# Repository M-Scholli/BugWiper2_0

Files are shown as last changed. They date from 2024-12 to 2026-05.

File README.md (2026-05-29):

## New ESP32-S3 Version

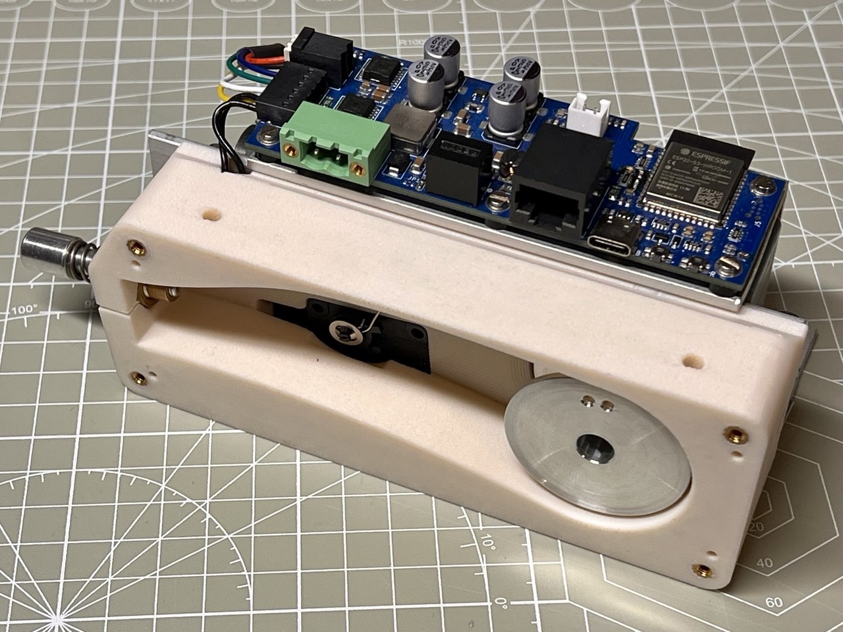
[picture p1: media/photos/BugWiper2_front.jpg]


The new version of the BugWiper system is a complete redesign of the hardware and software to improve the performance, reliability and features of the system. The new design is based on the ESP32-S3 micro controller. The new design also includes a new motor with higher torque, a self locking gear and a motor encoder to measure the motor position and speed. The new design also includes a new software architecture that allows for more advanced features like programmable cable length, soft direction change of the motor at the wingtip, slow down the motor before reaching the fuselage and logging of all sensor data on an SD-card for later analysis and optimization of the system.

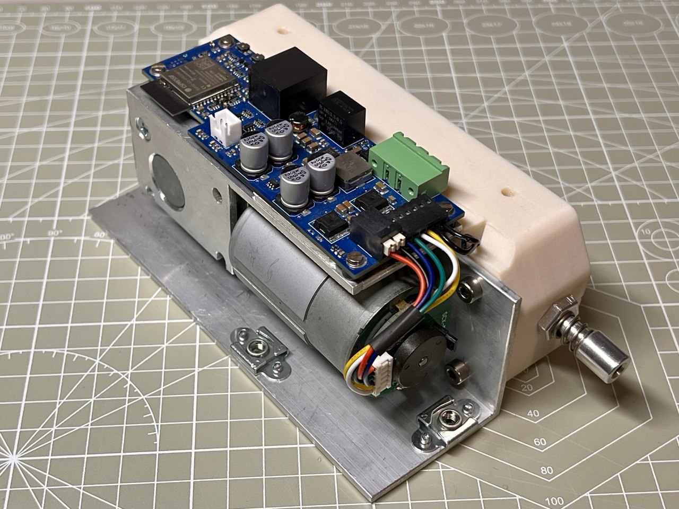
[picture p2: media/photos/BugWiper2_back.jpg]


The BugWiper System cleans the wings in around 30 seconds as shown in this graph:
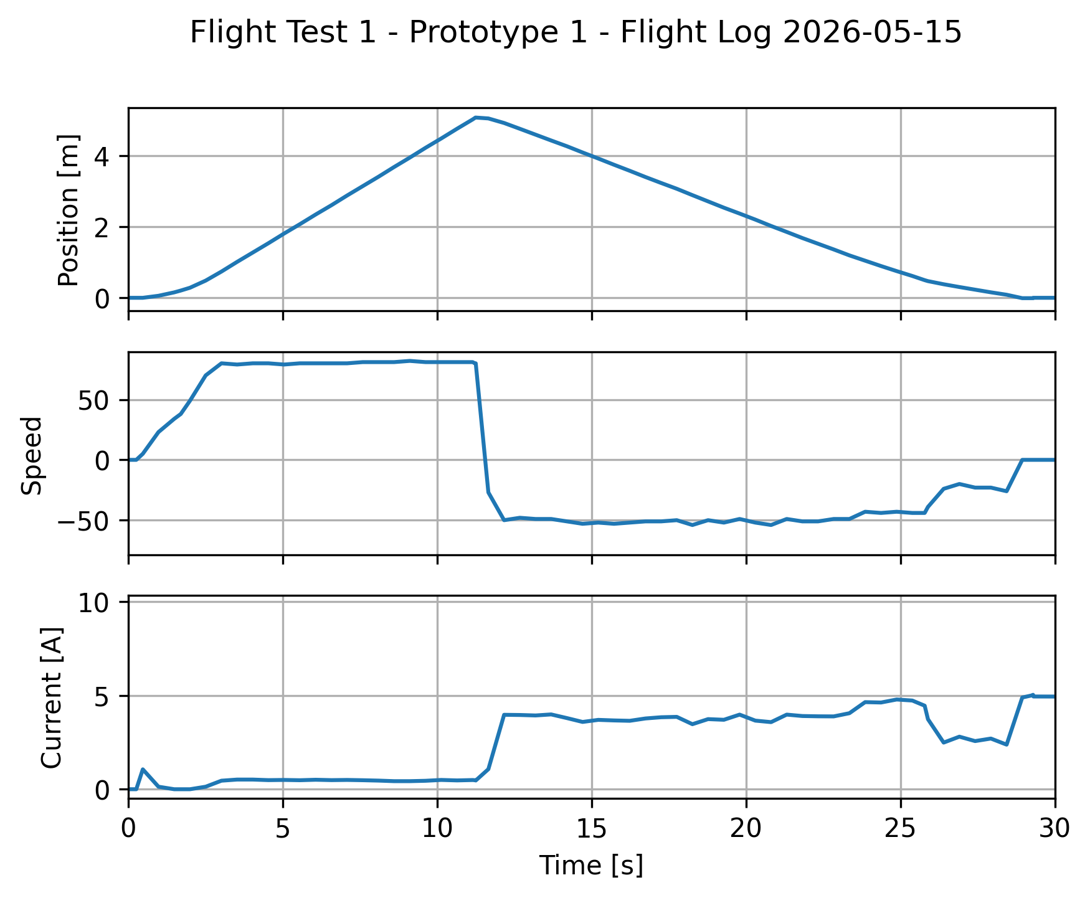
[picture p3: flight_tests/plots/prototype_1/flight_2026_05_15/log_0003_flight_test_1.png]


The documentation of the new version is still in progress, but you can already find some information about the hardware and software design in the following documents:
 [Documentation](./docs/doc.md)

 The user manual can be found here:
 [User Manual](./docs/user_manuel.md)

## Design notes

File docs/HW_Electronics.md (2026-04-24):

# Electronics

## PCB Design
- Designd in KiCAD 7
- 4 Layer PCB

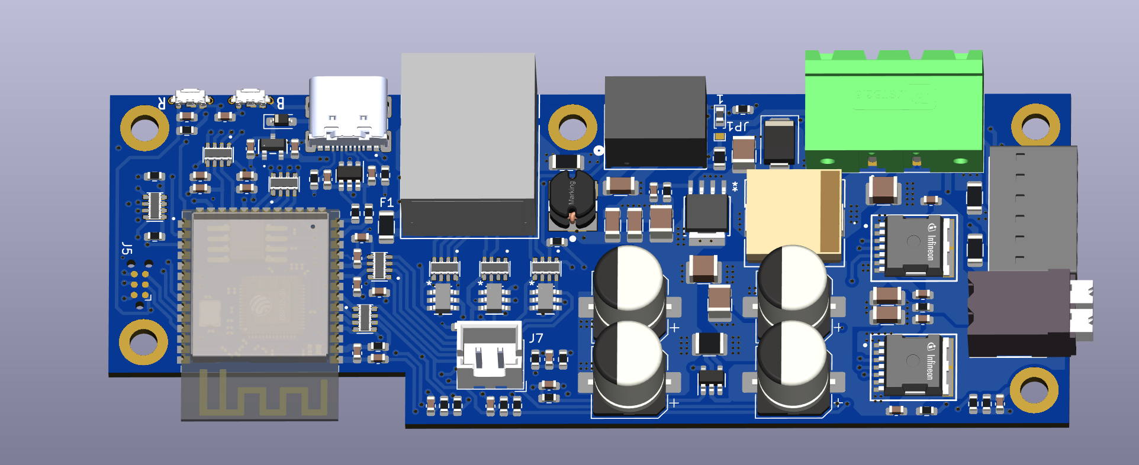
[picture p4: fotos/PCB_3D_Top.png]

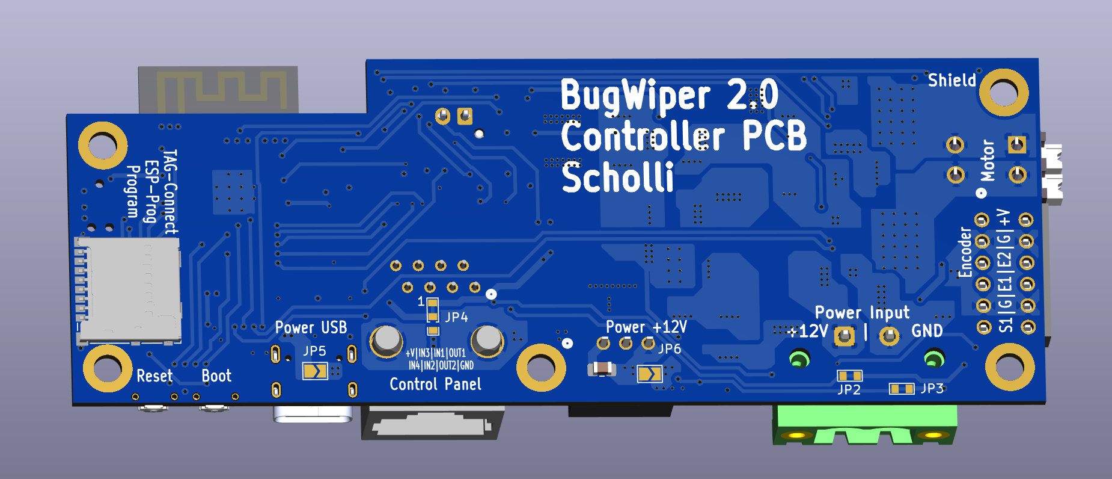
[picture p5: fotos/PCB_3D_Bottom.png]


## Circuit Diagram
[Schematics Controller PCB.pdf](../Hardware/ControllerPCB/BugWiper_ControllerPCB_SDT.pdf)
[Schematics Panel PCB.pdf](../Hardware/PanelPCB/BugWiper_Control_Panel_PCB_SDT.pdf)

## Key Components

| Name | Manufacturer|Function | Link |
| :---: | :---: |:---: | :----: |
|ESP32-S3-WROOM-1-N16R8|Espressif|Controller|https://mou.sr/4j57iPN|
|BTN9960LV|Infineon|Half Bridge with controller||
|INA180A2|texas instruments|Current Sense Amplifier||
|SQJ146ELP-T1_GE3|Vishay|N-MOSFET||
|UJ20-C-H-G-SMT-1-P16-TR |Same Sky|USB-C Connector|https://mou.sr/4adiw0M
| 1N5819HW-7-F | Diodes Incorporated|Schottky Diode 1A | https://mou.sr/3PtqzN7
|82400102|Würth|TVS Diode Array|
|EVP-AT2L1B000|Panasonic|switch|https://mou.sr/4j0OPno|

## Bill of Material
[BOM Controller PCB.csv](../Hardware/ControllerPCB/BugWiperPCB.csv)
[Bom Panel PCB.csv](../Hardware/PanelPCB/Panel/Panel.csv)

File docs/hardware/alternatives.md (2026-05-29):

# Suggestions for alternative hardware selection

## Controller
I suggest to use a ESP32-WROOM-32 or ESP32-S3-WROOM.

## ESP32-WROOM-32
Simple and small solution:
- diymore ESP32 WROOM 32 Nodemcu https://amzn.eu/d/j1bOF2C
### Pinout SP32-S3-DevKitC-1 N16R8:
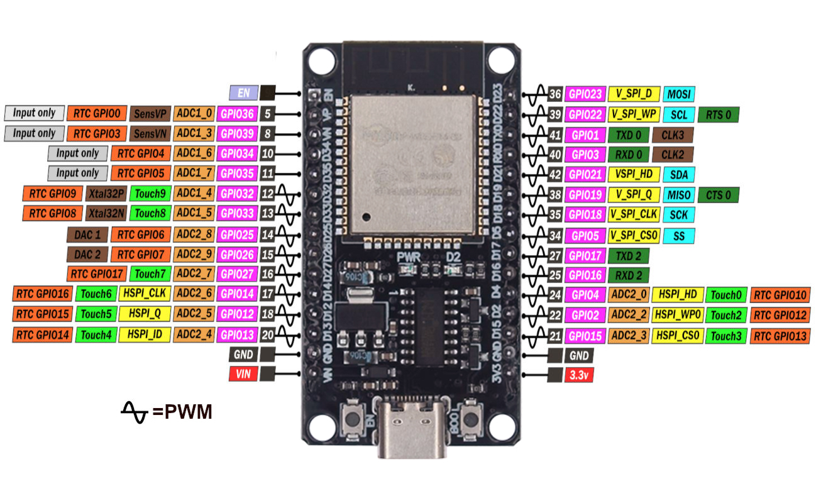
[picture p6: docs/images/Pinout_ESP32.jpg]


### CH340 Driver (USB-Serial)
https://www.arduined.eu/ch340-windows-10-driver-download/

## ESP32-S3-WROOM
newer ESP-S3:
- iHaospace 2 x ESP32-S3-DevKitC-1 N16R8 16Mb Flash, 8MB PSRAM https://www.amazon.de/dp/B0D1CBV999
### Pinout SP32-S3-DevKitC-1 N16R8:
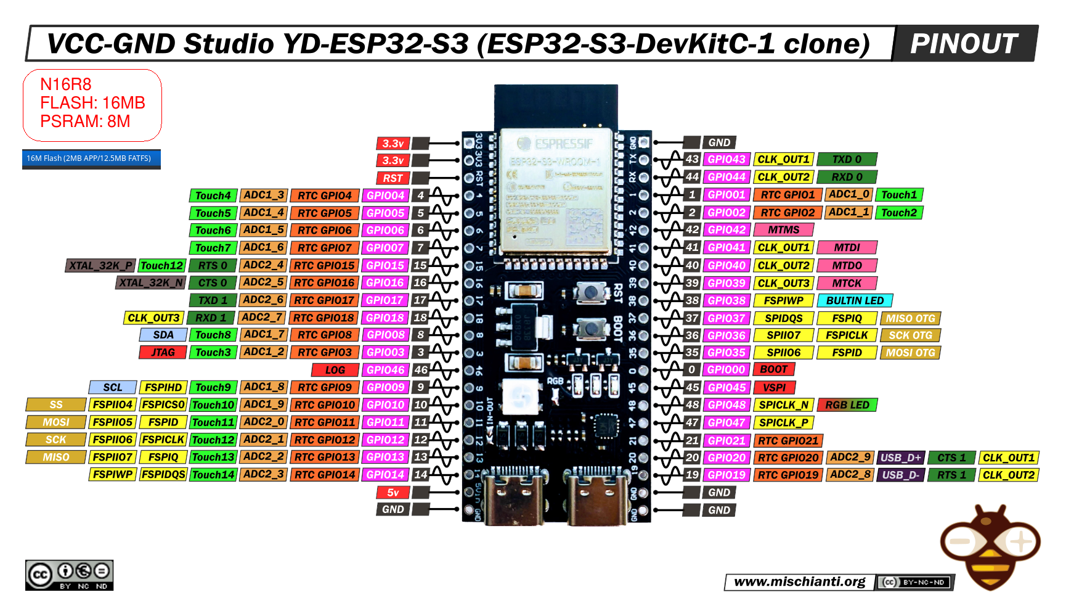
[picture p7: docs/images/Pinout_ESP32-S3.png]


## Motor controller / H-Bridge
### Complete Motor Driver PCB
#### IBT_2 BTS7960B 43 A Motor Driver: 
- https://www.makershop.de/module/motosteuerung/double-bts7960/
- https://www.amazon.de/dp/B09HGBM5D2

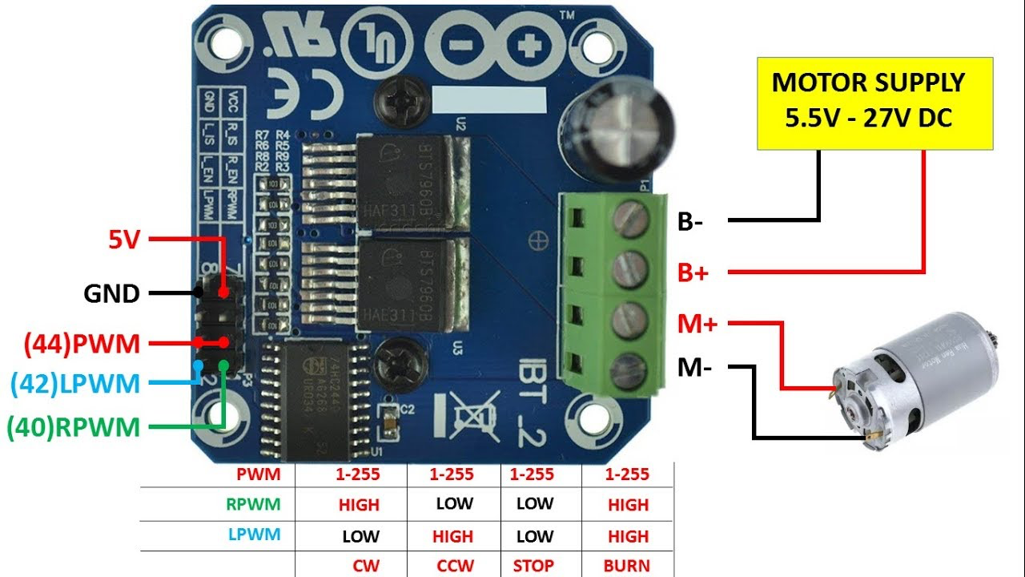
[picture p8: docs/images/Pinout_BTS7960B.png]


Specs:
- Max Current: 43 A
- Voltage Range: 5 V - 27 V
- Max PWM freq.: 25 kHz
- Current sensing output

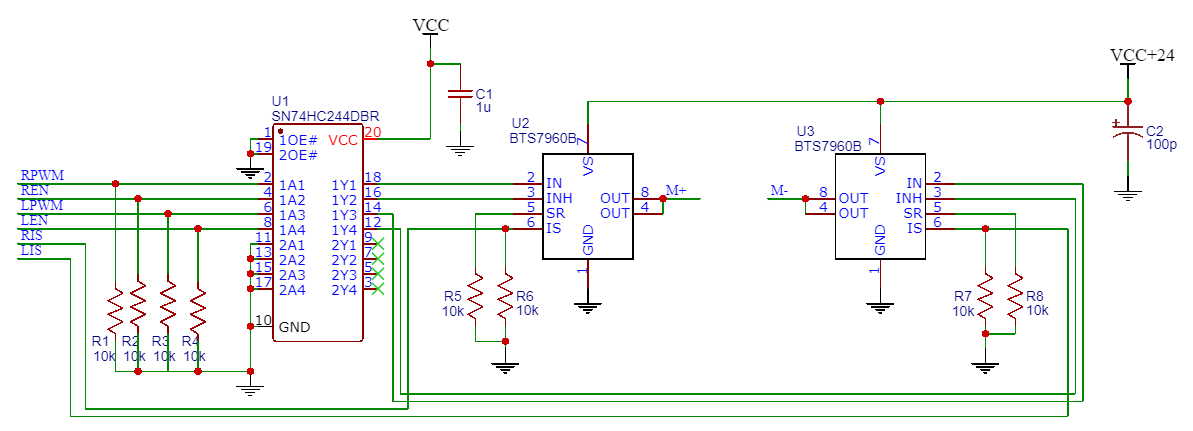
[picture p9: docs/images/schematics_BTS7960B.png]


### Others
- IBT_2 BTS7960B 43 A Motor Driver: https://www.amazon.de/dp/B09HGBM5D2
- 12V DC 200rpm High Torque Geared Electric Motor: https://www.amazon.de/gp/product/B00T48KC1Q 
- A3144 Linear Hall Effect Sensor: https://www.amazon.de/dp/B0BQ2Z335H
- Self-Adhesive Magnets 8 x 1 mm : https://www.amazon.de/dp/B0BJQ918KX

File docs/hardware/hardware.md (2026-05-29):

# Hardware Overview

- [Motor Selection and Tests](./motors.md)
- [PCB Design of the Controller and Panel PCB](./electronics.md)
- [Mechanical Construction](../mechanics/construction.md)
- [Suggestions for alternative hardware selection](./alternatives.md)
- [Documentation first Prototype](../testing/prototypes.md)

## Electronics / PCB Designs

### Motor Controller PCB


[More info here](./electronics.md)

### ControlPanel PCB
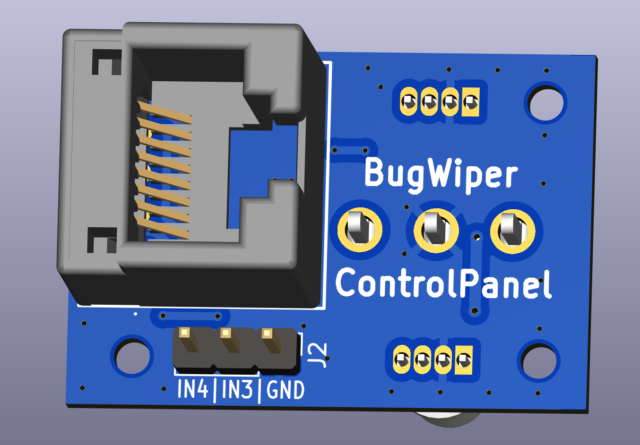
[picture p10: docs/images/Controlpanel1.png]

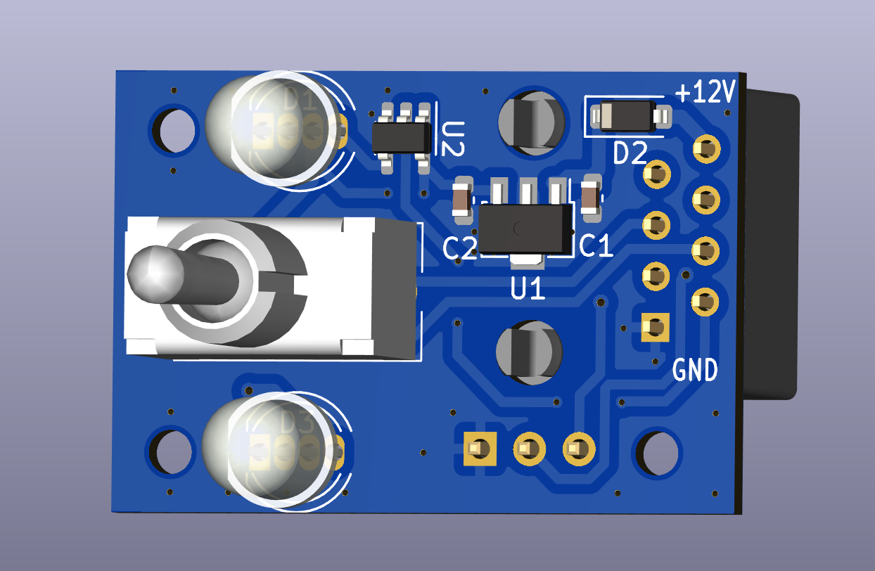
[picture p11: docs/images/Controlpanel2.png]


## Mechanical Construction
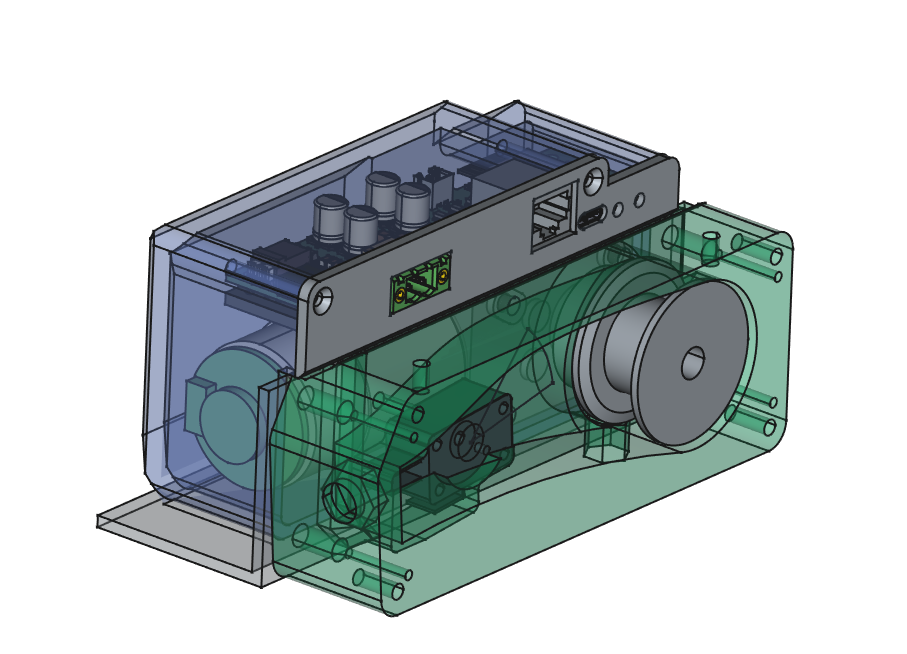
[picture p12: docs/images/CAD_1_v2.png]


- [Mechanical Construction](../mechanics/construction.md)

## Motor
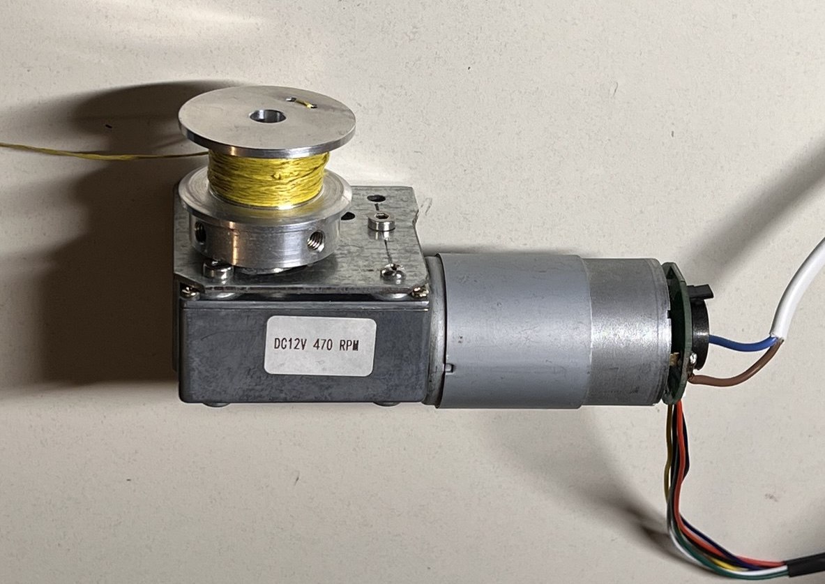
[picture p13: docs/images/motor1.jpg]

[More Details and Motor tests here](./motors.md)

## Old Version
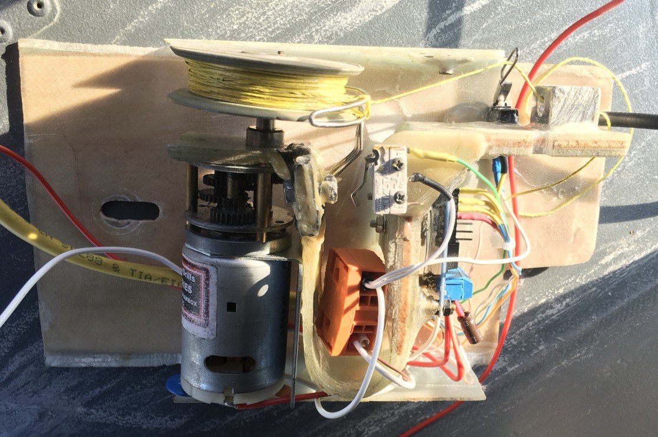
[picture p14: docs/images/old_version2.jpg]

[More information and documentation of the old prototypes and there problems can be found here](../old_version.md)
Also see the github repository of the old version:
[Old Version Repository](https://github.com/M-Scholli/BugWiper)

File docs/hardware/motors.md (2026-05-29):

# Motor

## Motor recommendations and comparison
In the Hardware folder of this repo is a [Excel](../../Hardware/Motor_comparison.xlsx)  and CSV file witch lots of motors and its comparison and the calculated winding times and forces at different drum diameters.
#### Motor selection criteria:
- Motor RPM between 250 to 450 RPM. This allows a cleaning time around 30 seconds with a spool diameter between 20 mm and 40 mm
- Motor Torque / Motor Power high enough to reach a pulling force of 3 to 5 kg
- high friction / high gear ratio / high no load current or self locking gear that the bug wiper wings don't pull out the rope when the motor is shut down. 

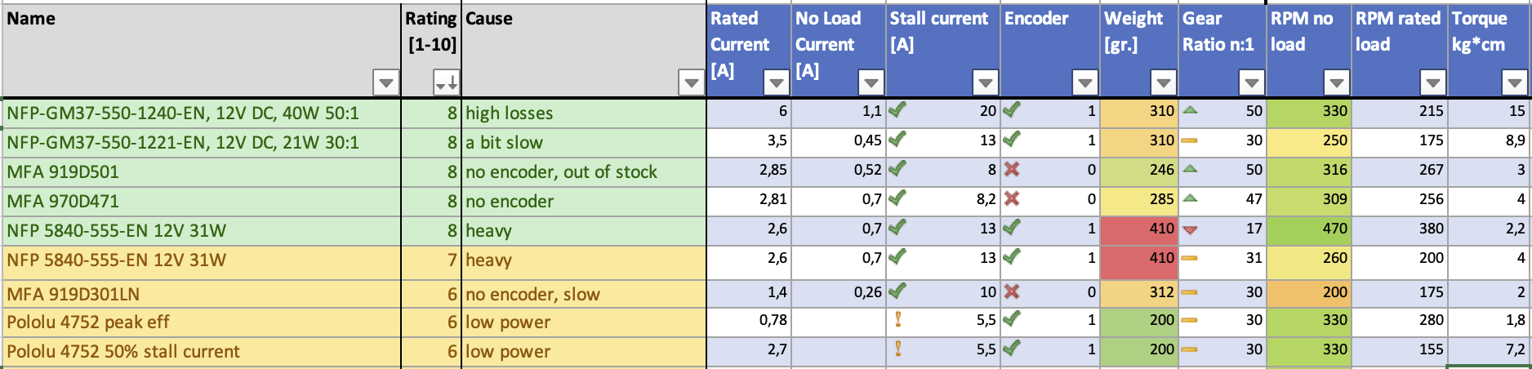
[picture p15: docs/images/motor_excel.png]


# Motor Tests:

## SRA58SW-555B / 5840-555 Worm Geared Motor

https://www.bringsmart.com/pd.jsp?id=110

similar to https://nfpshop.com/product/12v-24v-metal-gear-worm-gear-model-nfp-5840-555-en ???



### Motor Parameters:
- 12 Volt
- 30 Watt
- 470 rpm
- self locking worm gear
- 17:1 Gear ratio

### Testing

Cable drum with 24mm Diameter made out of CHANCS Aluminium Alloy Double V-Groove Belt Pulley 40 mm OD 8 mm Fixed Pulley for Motor Shaft Bore 6 mm: https://www.amazon.de/gp/product/B0CRR4KS3J

#### Forwards:
| Load| Current| Speed |
| :-- | :---: | ----: |
| 1kg | 2.2 A  | 0.55 m/s |
| 2kg | 3.4 A  | 0.44 m/s |
| 3kg |  4.6 A | 0.39 m/s |
| 4kg |  6.2 A | 0.32 m/s |
| 5kg |  8.3A | 0.23 m/s |

#### Backwards:
| Load| Current| Speed |
| :-- | :---: | ----: |
| 2kg |  4.6 A  | 0.4 m/s |
| 3kg |  6.4 A  | 0.37 m/s |

--> Time for the cleaning process of one wing around 28 seconds

### Result:
Positive:
+ self locking
+ high Torque
+ integrated Encoder
+ fast

Negative:
- high power consumption
- bad efficiency
- high noise
- higher losses when turning backwards

## ZGB37RH31 Motor 200 RPM
https://www.amazon.de/gp/product/B00T48KC1Q

https://www.zhengkemotor.com/product/Zhengk_DC_Brushed_Motor_RS555__EccentricShaft_37mm_Gearhead_RoundFlange_ZGB37RH.html

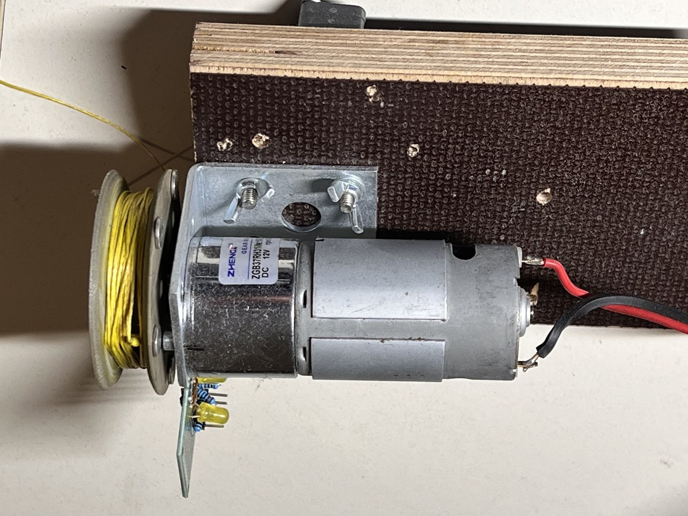
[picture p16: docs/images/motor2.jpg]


### Motor Parameters:
- 12 Volt
- 30 Watt
- 200 rpm
- self locking worm gear
- 31.1:1 Gear ratio

### Result:
Positive:
+ higher efficiency

Negative:
- not self locking, but could be enough resistance

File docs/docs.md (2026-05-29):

# BugWiper

This project is an open source electronic bug wiper system. 

## New ESP32-S3 Version

### New electronic design

- 32Bit ESP32-S CPU
    - Wifi
    - Bluetooth LE
    - USB
- motor encoder
- motor current measurement
- loose cable switch
- sd-card reader
- reverse voltage protection
- EMI-Filter
- efficient and low noise DC-DC converter
- protected in and outputs
  
### New control panel

- addressable RGB status LED
- 3-Pos momentary toggle switch
- 2-additional inputs and one output for future extensions like a canopy reed switch, a ground sensor or connection the BugWiper system of the other wing for synchronization.
- RJ45 connector for easy connection to the motor controller PCB and future extensions

### New mechanical design

- new motor with higher torque and self locking gear to prevent the bug wiper wings from pulling out the cable when the motor is powered off
- new deflection pully to reduce drag in the bowden tubes for sharp bend between the motor and the hole in the fuselage
- new cable drum with better cable guiding to prevent the cable from getting stuck in the drum

### New software design

- motor current sensor, input voltage, bug wiper speed and position decides when to stop the bug wiper motor
- programmable cable length with the motor encoder
- soft direction change of the motor at the wingtip. Motor turn every time the same direction for in and out.
- slow down the motor before reaching the fuselage to reduce the force at the stop.
- ground mode to loosen the bug wiper just bit and no full cleaning process
- wiggle mode to loosen the bug wiper if it is stuck at the fuselage
- logging of all sensor data on the sd-card for later analysis and optimization of the system

### Future features

- auto re-tighten the bug wipers if they loosen from the fuselage in flight (if a non self locking motor is used)
- WiFi Hotspot with web browser to configure the BugWiper system and do over the air updates before flight
- Config file on the SD-Kart or the internal flash of the ESP-32
- BLE for communication and logging
- Connection to Flarm or flight computer to get the speed of the plane for ground detection and the date and time for better logging.

# Software

[More information to setup the software and the code can be found here](./software/setup.md)
[Configuration and code documentation can be found here](./software/configuration.md)

# Hardware

[More information and documentation of PCB and mechanical construction can be found here](./hardware/hardware.md)
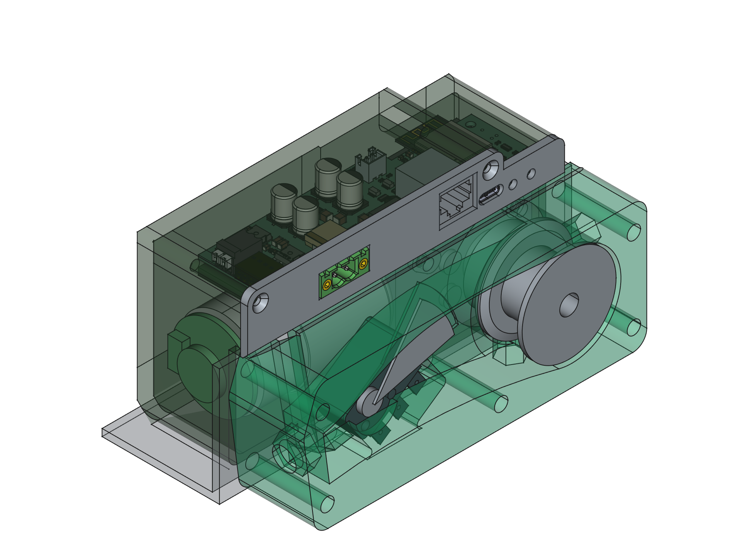
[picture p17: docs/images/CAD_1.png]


## Electronics / PCB Designs

### Motor Controller PCB



[More info here](./hardware/electronics.md)

### ControlPanel PCB




## Motor
[More Details and Motor tests here](./hardware/motors.md)

# Construction
[More information and documentation of mechanical construction can be found here](./mechanics/construction.md)

## Old Version
[More information and documentation of the old prototypes and there problems can be found here](./old_version.md)

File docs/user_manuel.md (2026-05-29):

# User Manual

## 1. Overview

This system is designed for:
- Automatic cleaning of the glider wings during flight with bug wipers
- Easy installation and maintenance
- Data logging for performance analysis and optimization
- Future-proof design for additional features and improvements

Main components:
- Bug wiper motor system
- Panel PCB (user interface)
- Bug Wipers (not part of this project yet, but the system is designed to work with standard bug wipers)

## 2. Getting Started
### Modes
the system has two modes:
- Normal Mode: Full cleaning process with automatic return and wiggle mode if the bug wipers are stuck at the fuselage
- Ground Mode: Loosens the bug wipers just one meter without a full cleaning process for ground handling

## 3. Operation

### Controls (Panel PCB)
The Control Panel has a 3-Pos momentary toggle switch for user interaction:

##### Normal Mode:
- Position 1 → Start cleaning (winding out)
- Position 3 → Return (winding in)

##### Ground Mode:
- Position 1 → Start loosening (after 2 seconds long press to prevent accidental activation)
- Position 3 → Return (winding in)

##### Stopping the process:
Witch pressing the opposite direction of the toggle switch the process can be stopped.

##### Emergency Winding In Mode:
With holding the toggle switch at Return the precess enters an emergency winding in mode, with overwrites stop conditions and enables the motor to wind in with full power until the toggle switch is released. This can be used if a sensor or software has a malfunction and the system stops to early.

## 4. Indicators

### RGB LED Status Indicator:

#### System Startup
- System initializes automatically and shows the configuration with the RGB LED with two short blinks and then turns black to save power.
- First blink: shows the Mode (Green for normal, orange for ground mode)
- Second blink: shows the SD-card status (Green for OK, orange for no SD-card for logging)

#### Cleaning Process:

- Green blinking → Running
- Yellow blinking → Cable Loose Mode / Wiggle Out
- Blue blinking → Wiggle In / Winding In
- Green long → Finished
- Red long → Error

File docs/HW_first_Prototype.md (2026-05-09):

# First Prototype

## PCB fixes config and versions
|Name|Change|Reason|PCB1|PCB2|
|--|---|---|---|---|
|Jp1|3.3V |Encoder|x|x|
|Jp2|closed||x|?|
|Jp3|closed||x|?|
|Jp4|12V Panel||x|?|
|Jp5|closed| 5V -> 3.3V|x|?|
|Jp6|closed| 12v -> 3.3V|x|?|
|C36|10nF --> 100nF|Filter Taster|?|x|
|C37| 10nF --> 1nF|Filter Encoder|x|x|
|C38|10nF --> 1nF|Filter ENcoder|x|x|
|C4|100nF --> 1uF|Reset Filter|no|x|
|C4|100nF --> 470nF|Reset Filter|x|no|

## PCB tests
|Test|Result PCB1| Result PCB2|
|--|---|---|
|Wing Side|R|L|
|Thermal Interface|OK|OK|
|Voltage Regulator 12V-3.3V|OK|OK|
|Voltage Regulator 5V-3.3V|OK|OK|
|Standby Current in mA|10|13|
|USB-C Port|OK|OK|
|Motor driver|OK|OK|
|Motor Encoder|OK|OK|
|SD Card|OK|OK|
|ButtonIN|OK|OK|
|ButtonOUT|OK|OK|
|RBG LED|OK|OK|
|Cable Loose Sensor|OK|OK|
|Ground Sensor|||
|Current Sensor|OK|OK|
|Voltage Sensor|OK|OK|
|Temperature Sensor|OK|OK|
|Current Sensor calibration|||
|Voltage Sensor calibration|||
|Motor Encoder calibration|||
|Ground Test after assembly|||

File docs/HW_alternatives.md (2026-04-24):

# Suggestions for alternative hardware selection

## Controller
I suggest to use a ESP32-WROOM-32 or ESP32-S3-WROOM.

## ESP32-WROOM-32
Simple and small solution:
- diymore ESP32 WROOM 32 Nodemcu https://amzn.eu/d/j1bOF2C
### Pinout SP32-S3-DevKitC-1 N16R8:


### CH340 Driver (USB-Serial)
https://www.arduined.eu/ch340-windows-10-driver-download/
### Board Settings:
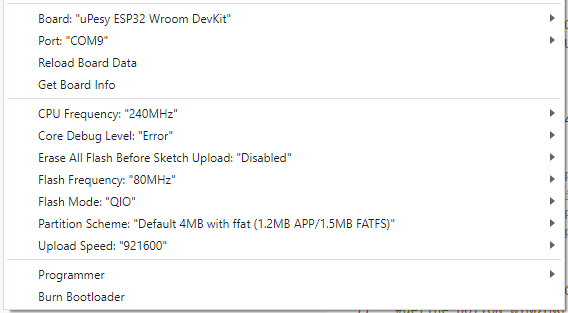
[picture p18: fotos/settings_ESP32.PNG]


## ESP32-S3-WROOM
newer ESP-S3:
- iHaospace 2 x ESP32-S3-DevKitC-1 N16R8 16Mb Flash, 8MB PSRAM https://www.amazon.de/dp/B0D1CBV999
### Pinout SP32-S3-DevKitC-1 N16R8:

### Board Settings:
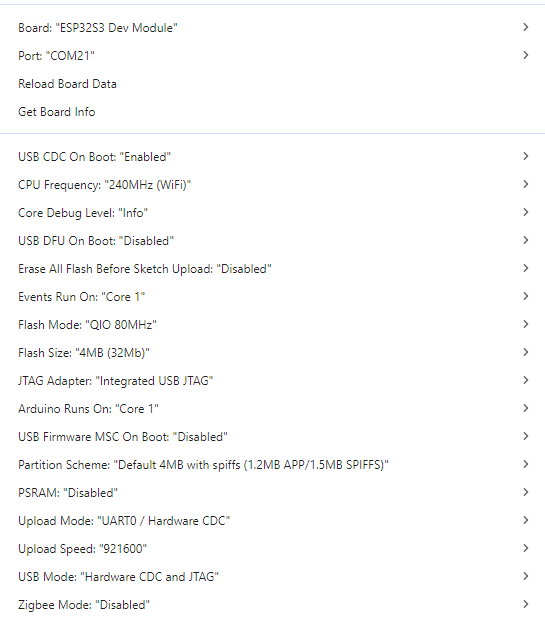
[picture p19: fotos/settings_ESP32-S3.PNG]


## Motor controller / H-Bridge
### Complete Motor Driver PCB
#### IBT_2 BTS7960B 43 A Motor Driver: 
- https://www.makershop.de/module/motosteuerung/double-bts7960/
- https://www.amazon.de/dp/B09HGBM5D2



Specs:
- Max Current: 43 A
- Voltage Range: 5 V - 27 V
- Max PWM freq.: 25 kHz
- Current sensing output



### Others
- IBT_2 BTS7960B 43 A Motor Driver: https://www.amazon.de/dp/B09HGBM5D2
- 12V DC 200rpm High Torque Geared Electric Motor: https://www.amazon.de/gp/product/B00T48KC1Q 
- A3144 Linear Hall Effect Sensor: https://www.amazon.de/dp/B0BQ2Z335H
- Self-Adhesive Magnets 8 x 1 mm : https://www.amazon.de/dp/B0BJQ918KX

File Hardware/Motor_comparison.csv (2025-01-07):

 |  |  |  |  |  |  |  |  | Drumm Diameter in mm : |  |  |  | 40 | 40 | 35 | 35 | 24 | 24 | 19 | 19
Name | Rating [1-10] | Cause | Rated Current [A] | No Load Current [A] | Stall current [A] | Encoder | Weight [gr.] | Gear Ratio n:1 | RPM no load | RPM rated load | Torque kg*cm | stall Tourque kg*cm | Force kg | t in s for 14m | Force kg2 | t in s for 14m3 | Force kg | t in s for 14m4 | Force kg 5 | t in s for 14m6 | number | link
NFP-GM37-550-1240, 12V DC, 40W 50:1 at 12% | 9 | high losses | 3,5 | 1,1 | 20 | 1 | 310 | 50 | 330 | 290,4 | 7,2 | 60 | 3,6 | 21,6 | 4,1 | 24,7 | 6,0 | 36,1 | 7,6 | 45,6 | 27,0 | https://dcmotorpro.com/product/37mm-metal-gear-motor-model-nfp-gm37-550-en
NFP-GM37-550-1240-EN, 12V DC, 40W 50:1 | 8 | high losses | 6 | 1,1 | 20 | 1 | 310 | 50 | 330 | 215 | 15 | 48 | 7,5 | 25,7 | 8,6 | 29,3 | 12,5 | 42,8 | 15,8 | 54,0 | 28,0 | https://dcmotorpro.com/product/37mm-metal-gear-motor-model-nfp-gm37-550-en
NFP-GM37-550-1221, 12V DC, 21W 50:1 at 25% | 9 | a bit slow | 3,7 | 0,45 | 13 | 1 | 310 | 50 | 250 | 187,5 | 8,9 | 33 | 4,5 | 31,2 | 5,1 | 35,7 | 7,4 | 52,0 | 9,4 | 65,7 | 30,0 | https://nfpshop.com/product/37mm-metal-gear-motor-model-nfp-gm37-545-en
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

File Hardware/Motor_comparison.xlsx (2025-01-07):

 |  |  |  |  |  |  |  |  | Drumm Diameter in mm : |  |  |  | 40 | 40 | 35 | 35 | 24 | 24 | 19 | 19
Name | Rating [1-10] | Cause | Rated Current [A] | No Load Current [A] | Stall current [A] | Encoder | Weight [gr.] | Gear Ratio n:1 | RPM no load | RPM rated load | Torque kg*cm | stall Tourque kg*cm | Force kg | t in s for 14m | Force kg2 | t in s for 14m3 | Force kg | t in s for 14m4 | Force kg 5 | t in s for 14m6 | number | link
NFP-GM37-550-1240-EN, 12V DC, 40W 50:1 | 8 | high losses | 6 | 1.1 | 20 | 1 | 310 | 50 | 330 | 215 | 15 | 48 | 7.5 | 25.7 | 8.6 | 29.3 | 12.5 | 42.8 | 15.8 | 54.0 | 28.0 | https://dcmotorpro.com/product/37mm-metal-gear-motor-model-nfp-gm37-550-en
NFP-GM37-550-1221-EN, 12V DC, 21W 30:1 | 8 | a bit slow | 3.5 | 0.45 | 13 | 1 | 310 | 30 | 250 | 175 | 8.9 | 33.05714286 | 4.5 | 32.5 | 5.1 | 37.1 | 7.4 | 54.1 | 9.4 | 68.4 | 31.0 | https://nfpshop.com/product/37mm-metal-gear-motor-model-nfp-gm37-545-en
MFA 919D501 | 8 | no encoder, out of stock | 2.85 | 0.52 | 8 | 0 | 246 | 50 | 316 | 267 | 3 | 48 | 1.5 | 23.1 | 1.7 | 26.4 | 2.5 | 38.5 | 3.2 | 48.6 | 6.0 | https://www.mfacomodrills.com/pdfs/919D-series.pdf
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

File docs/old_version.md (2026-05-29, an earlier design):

## Old Version
### Version 1
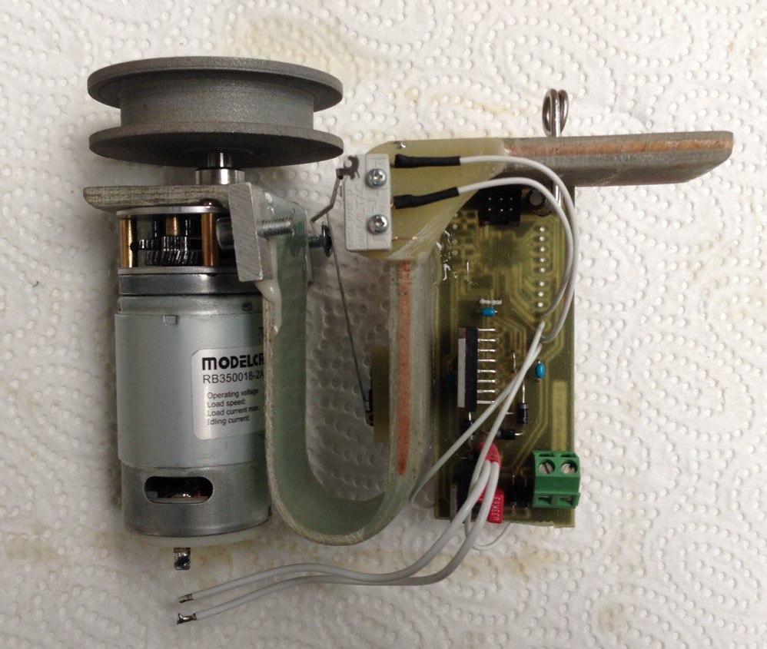
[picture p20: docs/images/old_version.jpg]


[Link to the old version repository](https://github.com/M-Scholli/BugWiper)

- Modelcraft RB350018-2A723R Hochleistungsgetriebemotor 12 V 18:1 :https://www.conrad.de/de/p/modelcraft-rb350018-2a723r-hochleistungsgetriebemotor-12-v-18-1-233131.html
- dual H-Bridge Motor driver L298 3A
- 45mm Diameter Cable Drum

#### Problems:
- Motor Driver had a high voltage drop, which reduced the motor power
- Motor was not enough torque for higher speeds
- Motor was to easy to rotate when powered off. The spring in the bug wiper wings pulled the cable out a bit.
- The GFK spring pulled out the cable after stopping the motor and turned the motor backwards
- the GFK spring is not only bending as intended, but although twisting dependent on the spooling direction of the cable drum. This results that the outboard stop switch is reached at 5-6 kg in one direction and at 2-3 kg in the other direction. So that in one direction the Motor not automatically stops when the bug wiper wings reaching the fuselage and in the other direction the motor stops all the time in the middle of the wing.
- The high pull force of the cable tightens the cable sometimes so strong, that at the next winding out the windings are pressed so strong together, that the spool is pulling the wings back inwards after a couple of rotations

### Version 1.1


#### Features:
- new higher geared motor for more torque and more resistance when powered off 
- new high power motor driver

#### Components:
- MFA 919D1481 Geared Motor 12 V/DC 148:1 https://amzn.eu/d/hulJdEZ
- Arduino Nano
- IBT_2 BTS7960B 43 A Motor Driver: https://www.amazon.de/dp/B09HGBM5D2

#### Problems:
- new motor is very slow
- still the same Problems with the cable and the GFK spring

### Panel
 - one LED per Wing
 - one two-way toggle-switch
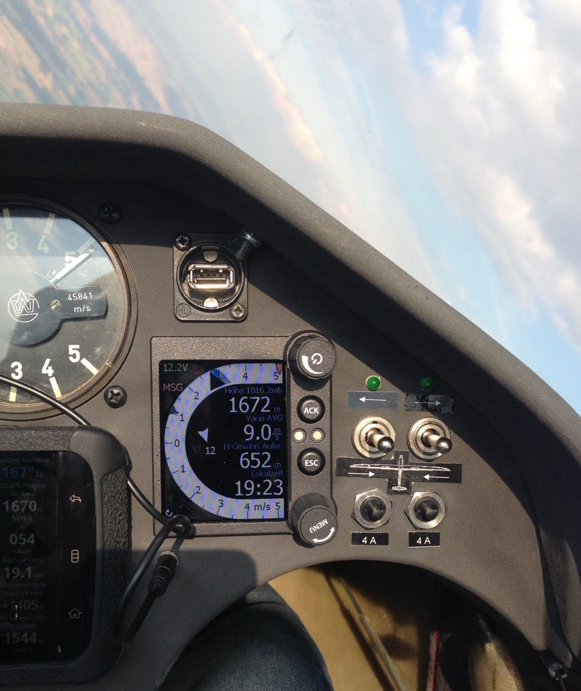
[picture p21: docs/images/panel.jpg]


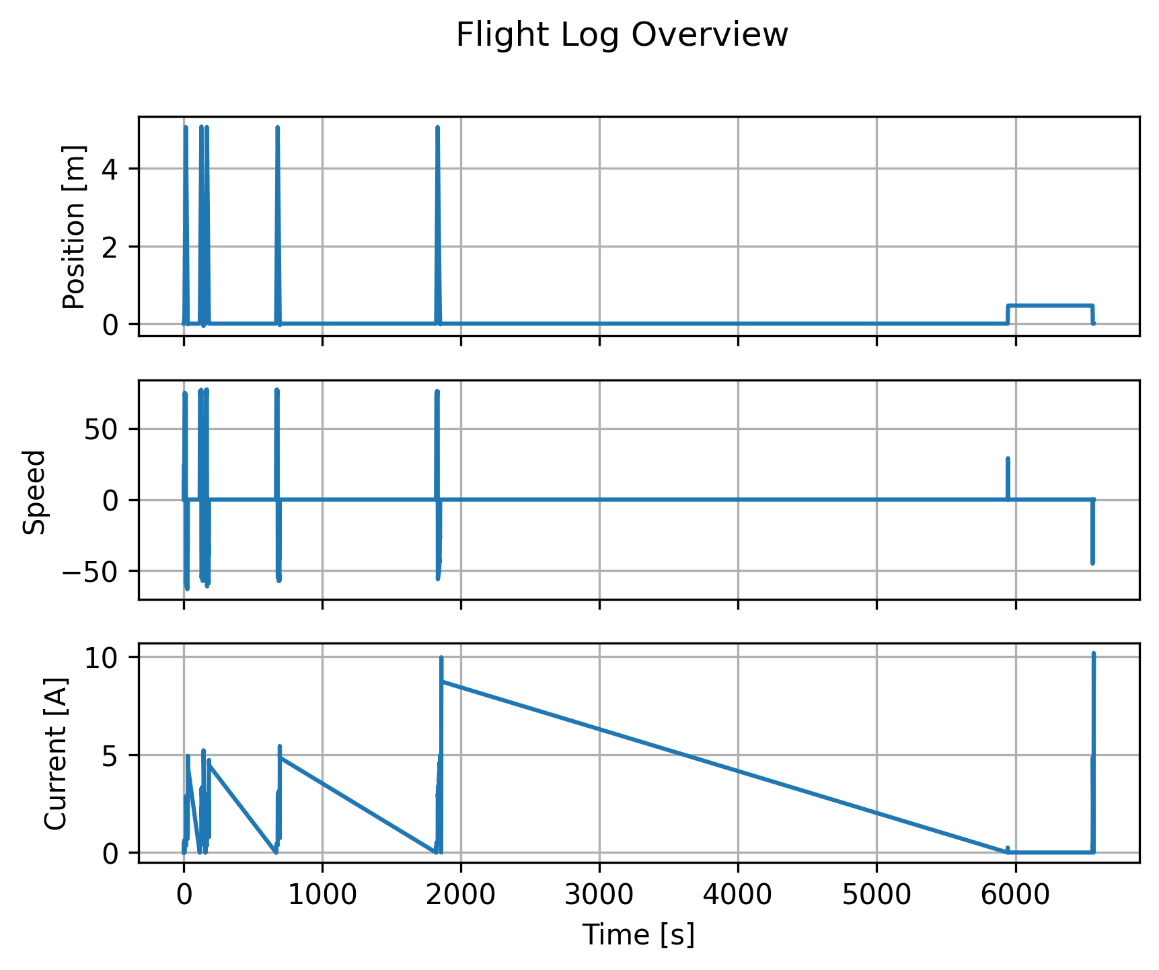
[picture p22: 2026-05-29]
flight_tests/plots/prototype_2/flight_2026_05_15/log_0011_flight_overview.png

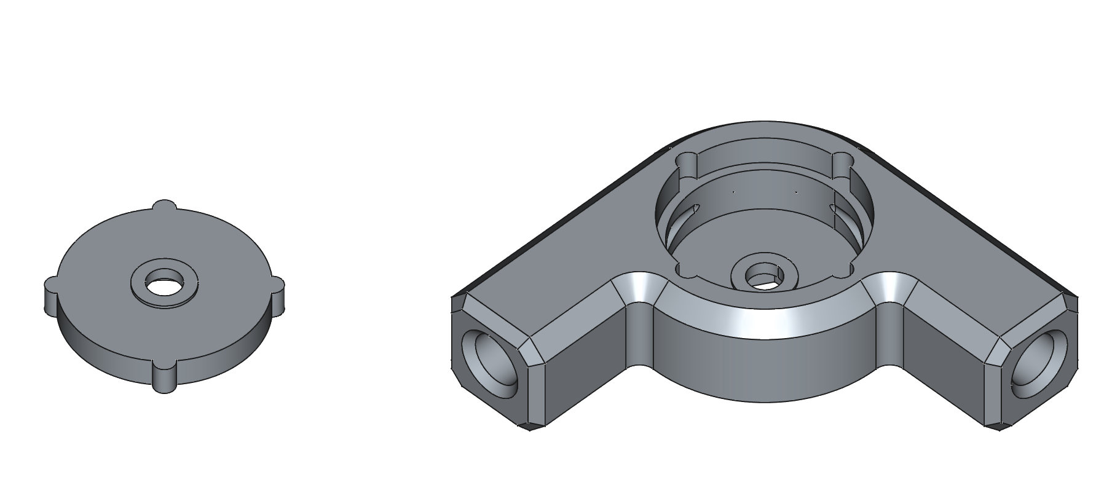
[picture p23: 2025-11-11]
docs/images/CAD_Pulley.png

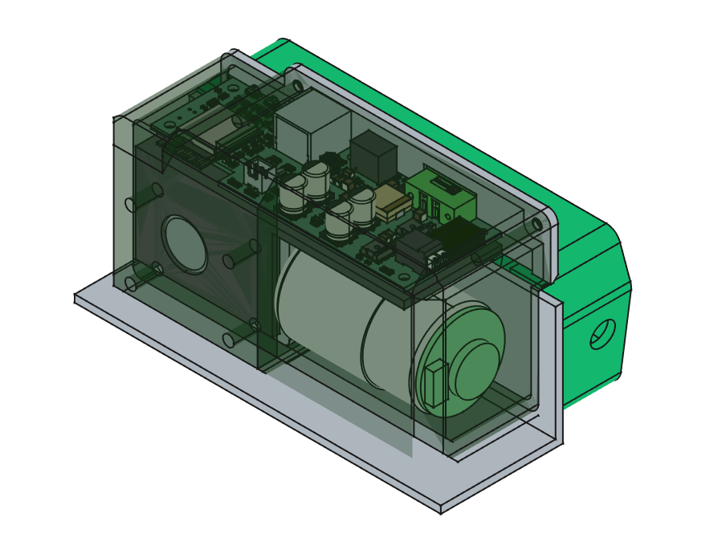
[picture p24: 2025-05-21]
docs/images/CAD_2.png

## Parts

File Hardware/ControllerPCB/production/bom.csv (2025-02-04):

Designator | Footprint | Quantity | Value | LCSC Part #
C10, C24, C25, C26, C7 | 1206 | 5 | 22uF 25V
C11, C12, C13 | 0603 | 3 | 1nF
C14, C32, C33, C34, C35, C36, C37 | 0603 | 7 | 10nF
C15, C16, C17, C21, C23 | 1210 | 5 | 22uF 25V
C18, C19, C20, C28 | CP_Elec_8x10.5 | 4 | 470uF 16V
C22, C27, C29, C3, C30, C31, C38, C39, C4 | 0603 | 9 | 100nF
C40, C5, C9 | 0805 | 3 | 1uF 50V
CR1, CR2, CR3, CR4 | SOT26_DIO | 4 | D5V0P4UR6SO-7
D1 | D_SOD-323_HandSoldering | 1 | CUS15S30,H3F
D2 | D_SOD-323_HandSoldering | 1 | D_Zener 10V
D3 | D_SMB | 1 | D_TVS 15V
F1, F2, F3, F4 | 1206 | 4 | 100mA Polyfuse
H1, H2, H3, H4 | MountingHole_3.2mm_M3_DIN965_Pad | 4 | MountingHole
H5 | MountingHole_3.2mm_M3_DIN965_Pad_TopBottom | 1 | MountingHole_Pad
J1 | SAMESKY_UJ20-C-H-G-SMT-1-P16-TR | 1 | UJ20-C-H-G-SMT-1-P16-TR
J2 | CONN_1814537 | 1 | 1770924
J3 | PHOENIX_1776508 | 1 | Phoenix_1776508
J4 | CONN8_2-908LF_AMP | 1 | RJ45
J6 | SHDR4W80P700X350_2X2_770X1400X850P | 1 | 1824420000
J7 | JST_XH_B2B-XH-AM_1x02_P2.50mm_Vertical | 1 | Conn_01x02_Pin
J8 | microSD_HC_Molex_104031-0811 | 1 | Micro_SD_Card
JP1 | SolderJumper_R_SMD_0603 | 1 | SolderJumper_3_Open
JP2, JP3 | SolderJumper_2P_R_SMD_0603_Bridged | 2 | Bridged 12
JP4 | SolderJumper_3P_R_SMD_0603_Bridged_12 | 1 | SolderJumper_3_Bridged12
JP5, JP6 | SolderJumper-2_P1.3mm_Open_TrianglePad1.0x1.5mm | 2 | SolderJumper_2_Open
L1 | IND_IHLP-4040DZ_VIS | 1 | IHLP4040DZER100M1A
L2 | WE-PD2_5848 | 1 | 10µH 2.2A
Q1 | PowerPAK_SO-8L_3_VIS | 1 | SQJ146ELP-T1_GE3
R10, R11, R18, R21, R22, R38, R6 | 0603 | 7 | 10k
R12, R13, R14, R15, R27, R9 | 0603 | 6 | 1k
R19 | 0603 | 1 | 3k3
R2, R3 | 0603 | 2 | 5k1
R20 | 0603 | 1 | 22k
R25 | 1210 | 1 | R004
R4, R5 | 0603 | 2 | 22
RN1, RN2, RN5 | RESCAV80P320X155X60-8N | 3 | 1k x 4
RN3, RN6, RN7 | RESCAV80P320X155X60-8N | 3 | 100R x 4
RN4, RN8 | RESCAV80P320X155X60-8N | 2 | 10k x 4
S1, S2 | SW_EVP-AT2L1B000 | 2 | EVP-AT2L1B000
TH1 | 0603 | 1 | Thermistor_NTC
U1 | ESP32-S3-WROOM-1 | 1 | ESP32-S3-WROOM-1
U2, U3 | IFX-PG-HSOF-7-1-V | 2 | BTN9960LV
U4 | SOT-23-5 | 1 | INA180A2
U6 | TSR0P5_TRP | 1 | TSR 0.5-2433
U7 | SOT23R_DIO | 1 | AP7333-33SRG-7

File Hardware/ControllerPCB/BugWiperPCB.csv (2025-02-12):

Source: | /Users/scholli/Git/BugWiper2_0/Hardware/ControllerPCB/BugWiperPCB.kicad_sch
Date: | Thursday, February 13, 2025 at 12:04:14 AM
Tool: | Eeschema 7.0.10
Generator: | /Applications/KiCad/KiCad.app/Contents/SharedSupport/plugins/bom_csv_grouped_by_value_with_fp Mouser.py
Component Count: | 96
Ref | Qnty | Value | Cmp name | Footprint | Description | Manufacturer_Name | Manufacturer_Part_Number | Mouser Part Number | Mouser Price/Stock | JLCPCB PART# | JLCPCB Price | DNP
C3, C4, C22, C27, C29, C30, C31, C38, C39 | 9 | 100nF | C | Capacitor_SMD:C_0603_1608Metric | Unpolarized capacitor | Samsung | CL10B104KB8NNNC | 187-CL10B104KB8NNNC | 0,01 €
C5, C9, C40 | 3 | 1uF 50V | C | Capacitor_SMD:C_0805_2012Metric | Unpolarized capacitor | Samsung | CL21B105MBFNNNE | 187-CL21B105MBFNNNE | 0,026€
C7, C10, C24, C25, C26 | 5 | 22uF 25V | C | Capacitor_SMD:C_1206_3216Metric | Unpolarized capacitor | Samsung | CL31A226KAHNNNE | 187-CL31A226KAHNNNE | 0,20€
C11, C12, C13 | 3 | 1nF | C | Capacitor_SMD:C_0603_1608Metric | Unpolarized capacitor | KYOCERA AVX | KAM15AR71H102KM | 581-KAM15AR71H102KM | 0,036€
C14, C32, C33, C34, C35, C36, C37 | 7 | 10nF | C | Capacitor_SMD:C_0603_1608Metric | Unpolarized capacitor | Samsung | CL10B103KB8NFNC | 187-CL10B103KB8NFNC | 0,016 €
C15, C16, C17, C21, C23 | 5 | 22uF 25V | C | Capacitor_SMD:C_1210_3225Metric | Unpolarized capacitor | Samsung | CL31A226KAHNNNE | 187-CL31A226KAHNNNE | 0,20€
C18, C19, C20, C28 | 4 | 330uF 25V | C_Polarized | Capacitor_SMD:CP_Elec_8x10.5 | Polarized capacitor | Nichicon | UWT1E331MNL1GS | 647-UWT1E331MNL1S | 0,256€
CR1, CR2, CR3, CR4 | 4 | D5V0P4UR6SO-7 | D5V0P4UR6SO-7 | BugWiper_lib:SOT26_DIO |  | Diodes Incorporated | D5V0P4UR6SO-7 | 621-D5V0P4UR6SO-7 | 0,233€
D1 | 1 | CUS15S30,H3F | 1N5819WS | Diode_SMD:D_SOD-323_HandSoldering | 40V 600mV@1A 1A SOD-323 Schottky Barrier Diodes, SOD-323 | TOSHIBA | CUS15S30,H3F | 757-CUS15S30H3F | 0,209€
D2 | 1 | GDZ10B-E3-08 | D_Zener | Diode_SMD:D_SOD-323_HandSoldering | Zener diode | Vishay | GDZ10B-E3-08 | 78-GDZ10B-E3-08 | 0,143 €
D3 | 1 | D_TVS 14V | D_TVS | Diode_SMD:D_SMB | Bidirectional transient-voltage-suppression diode | Diodes Incorporated | SMBJ14CA-13-F | 621-SMBJ14CA-13-F | 0,219 €
F1, F2, F3, F4 | 4 | PTS120630V012 | Polyfuse | Resistor_SMD:R_1206_3216Metric | Resettable fuse, polymeric positive temperature coefficient | Eaton Electronics | PTS120630V012 | 504-PTS120630V012 | 0,108€
J1 | 1 | UJ20-C-H-G-SMT-1-P16-TR | UJ20-C-H-G-SMT-1-P16-TR | BugWiper_lib:SAMESKY_UJ20-C-H-G-SMT-1-P16-TR |  | Same Sky | UJ20-C-H-G-SMT-1-P16-TR | 179-UJ20CHGSMT1P16TR | 0,494 €
J2 | 1 | 1770924 | 1770924 | CONN_1814537 |  | Phoenix Contact | 1770924 | 651-1770924 | 1,29 €
J3 | 1 | 1776508 | Phoenix_1776508 | BugWiper_lib:PHOENIX_1776508 |  | Phoenix Contact | 1776508 | 651-1776508 | 1,83 €
J4 | 1 | 54602-908LF | RJ45_Shielded | BugWiper_lib:CONN8_2-908LF_AMP | RJ connector, 8P8C (8 positions 8 connected), Shielded | Amphenol FCI | 54602-908LF | 649-54602-908LF | 0,551 €
J6 | 1 | 1824420000 | 1824420000 | BugWiper_lib:SHDR4W80P700X350_2X2_770X1400X850P | Printed circuit board terminals, 3.50 mm, Number of poles: 2, 90, Solder pin length: 3.5 mm, black, PUSH IN with actuator, Clamping range, max. [rated connection]: 1.5 mm, Tube | Weidmuller | 1824420000 | 470-1824420000 | 1,11 €
J8 | 1 | 104031-0811 | Micro_SD_Card_Det2 | BugWiper_lib:microSD_HC_Molex_104031-0811 | Micro SD Card Socket with two card detection pins | Molex | 104031-0811 | 538-104031-0811 | 1,90 €
J9 | 1 | 1873207 | Conn_01x02_Socket |  | Generic connector, single row, 01x02, script generated | Phoenix Contact | 1873207 | 651-1873207 | 2,51€
L1 | 1 | IHLP4040DZER100M11 | IHLP4040DZER100M1A | BugWiper_lib:IND_IHLP-4040DZ_VIS |  | Vishay | IHLP4040DZER100M11 | 70-IHLP4040DZER100M1 | 1,18 €
L2 | 1 | 10uH 2.2A 74477410 | WE-PD2_5848 | BugWiper_lib:WE-PD2_5848 |  | Wurth Elektronik | 74477410 | 710-74477410 | 1,61€ |  | 0.1270
Q1 | 1 | SQJ146ELP-T1_GE3 | NMOS_SO-8 | BugWiper_lib:PowerPAK_SO-8L_3_VIS | N-MOSFET transistor, drain/gate/source | Vishay | SQJ146ELP-T1_GE3 | 78-SQJ146ELP-T1_GE3 | 1,02 €
R2, R3 | 2 | 5k1 | R | Resistor_SMD:R_0603_1608Metric | Resistor | YAGEO | RC0603FR-105K1L | 603-RC0603FR-105K1L | 0,008 €
R4, R5 | 2 | 22 | R | Resistor_SMD:R_0603_1608Metric | Resistor | Bourns | CR0603-FX-22R0ELF | 652-CR0603FX-22R0ELF | 0,009 €
R6, R10, R11, R18, R21, R22, R38 | 7 | 10k | R | Resistor_SMD:R_0603_1608Metric | Resistor | YAGEO | RC0603FR-1010KL | 603-RC0603FR-1010KL | 0,008 €
R7, R8, R20 | 3 | 22k | R | Resistor_SMD:R_0603_1608Metric | Resistor | YAGEO | AC0603FR-1022KL | 603-AC0603FR-1022KL | 0,01 €
R9, R12, R13, R14, R15, R27 | 6 | 1k | R | Resistor_SMD:R_0603_1608Metric | Resistor | YAGEO | RC0603FR-071KL | 603-RC0603FR-071KL | 0,009 €
R19 | 1 | 3k3 | R | Resistor_SMD:R_0603_1608Metric | Resistor | Bourns | CR0603-FX-3301ELF | 652-CR0603-FX3301ELF | 0,009 €
R25 | 1 | R004 | R | Resistor_SMD:R_1210_3225Metric | Resistor | Welwyn Components / TT Electronics | LRMAM1206-R004FT5 | 756-LRMAM1206R004FT5 | 0,57 €
RN1, RN2, RN5 | 3 | 1k x 4 | R_Pack04 | BugWiper_lib:RESCAV80P320X155X60-8N | 4 resistor network, parallel topology | Bourns | CAY16-1001F4LF | 652-CAY16-1001F4LF | 0,034 € |  | 0.0138
RN3, RN6, RN7 | 3 | 100R x 4 | R_Pack04_Split | BugWiper_lib:RESCAV80P320X155X60-8N | 4 resistor network, parallel topology, split | Bourns | CAT16A-1000F4LF | 652-CAT16A-1000F4LF | 0,098 € |  | 0.0051
RN4, RN8 | 2 | 10k x 4 | R_Pack04 | BugWiper_lib:RESCAV80P320X155X60-8N | 4 resistor network, parallel topology | Bourns | CAT16A-1002F4LF | 652-CAT16A-1002F4LF | 0,085 € |  | 0.0053
SW1, SW2 | 2 | SW_Push | SW_Push | BugWiper_lib:EVQ9P701P | Push button switch, generic, two pins | Panasonic | EVQ-P3401P | 667-EVQP3401P | 0,228€
TH1 | 1 | 10k NTC | Thermistor_NTC | Resistor_SMD:R_0603_1608Metric | Temperature dependent resistor, negative temperature coefficient | Murata | NCU18XH103E60RB | 81-NCU18XH103E60RB | 0,095 €
U1 | 1 | ESP32-S3-WROOM-1 | ESP32-S3-WROOM-1 | BugWiper_lib:ESP32-S3-WROOM-1 | 2.4 GHz WiFi (802.11 b/g/n) and Bluetooth ® 5 (LE) module Built around ESP32S3 series of SoCs, Xtensa ® dualcore 32bit LX7 microprocessor Flash up to 16 MB, PSRAM up to 8 MB 36 GPIOs, rich set of peripherals Onboard PCB antenna | Espressif Systems | ESP32-S3-WROOM-1-N16R8 | 356-ESP32S3WRM1N16R8 | 3,71 €
U2, U3 | 2 | BTN9960LV | BTN9960LV_1 | BugWiper_lib:IFX-PG-HSOF-7-1-V | High Current PN Half-Bridge with Integrated Driver | infineon | BTN9960LVAUMA1 | 726-BTN9960LVAUMA1 | 2,40 €
U4 | 1 | INA180A2 | INA180A2 | Package_TO_SOT_SMD:SOT-23-5 | Current Sense Amplifier, 1 Circuit, Rail-to-Rail, 26V, Gain 50 V/V, SOT-23-5 | texasinstruments | INA180A2IDBVT | 595-INA180A2IDBVT | 0,855€ |  | 0.2074
U6 | 1 | TSR 0.5-2433 | TSR_0.5-2433 | BugWiper_lib:TSR0P5_TRP |  | RECOM | R-78E3.3-0.5 | 919-R-78E3.3-0.5 | 2,75€
U7 | 1 | AP7333-33SRG-7 | AP7333-33SRG-7 | SOT23R_DIO |  | Diodes Incorporated | AP7333-33SRG-7 | 621-AP7333-33SRG-7 | 0,314 €

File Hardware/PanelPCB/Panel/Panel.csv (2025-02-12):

Source: | /Users/scholli/Git/BugWiper2_0/Hardware/PanelPCB/Panel/Panel.kicad_sch
Date: | Thursday, February 13, 2025 at 12:35:27 AM
Tool: | Eeschema 7.0.10
Generator: | /Applications/KiCad/KiCad.app/Contents/SharedSupport/plugins/bom_csv_grouped_by_value_with_fp Mouser.py
Component Count: | 10
Ref | Qnty | Value | Cmp name | Footprint | Description | Manufacturer_Name | Manufacturer_Part_Number | Mouser Part Number | Mouser Price/Stock | JLCPCB PART# | JLCPCB Price | DNP
C1, C3 | 2 | 100nF | C | Capacitor_SMD:C_0603_1608Metric | Unpolarized capacitor | Samsung Electro-Mechanics | CL10B104KB8NNNC | 187-CL10B104KB8NNNC
C2 | 1 | 470nF | C | Capacitor_SMD:C_0603_1608Metric | Unpolarized capacitor | Samsung Electro-Mechanics | CL10B474KA8NFNC | 187-CL10B474KA8NFNC | 0,038 €
D1 | 1 | APA-106-F5 | APA-106-F5 | LED_THT:LED_D5.0mm-4_RGB_Wide_Pins | RGB LED with integrated controller, 5mm Package | SparkFun | APA-106-F5
D2 | 1 | CUS15S30,H3F | 1N4148W | Diode_SMD:D_SOD-323_HandSoldering | 75V 0.15A Fast Switching Diode, SOD-123 | Toshiba | CUS15S30,H3F | 757-CUS15S30H3F | 0,209 €
J1 | 1 | RJ45 | RJ45 | BugWiper_lib:MJ3415882 | RJ connector, 8P8C (8 positions 8 connected) | GCT | MJ3415-88-2 | 640-MJ3415-88-2 | 0,599 €
L1 | 1 | L_Ferrite | L_Ferrite | Inductor_SMD:L_0805_2012Metric | Inductor with ferrite core | Vishay / Dale | ILBB0805ER151V | 70-ILBB0805ER151V | 0,095 €
S1 | 1 | 100SP4T1B4M2QE | 100SP4T1B4M2QE | 100SP4T1B4M2QE | TOGGLE, 5A, 120VAC/28VDC SPDT, (On)-Off-(On) Through Hole | E-Switch | 100SP4T1B4M2QE | 612-100SP4T1B4M2QE | https://www.mouser.com/Search/Refine.aspx?Keyword=612-100SP4T1B4M2QE
U1 | 1 | AP2204R-5.0 | AP2204R-5.0 | Package_TO_SOT_SMD:SOT-89-3 | 150mA low dropout linear regulator, wide input voltage range, 5.0V fixed positive output, SOT-89-3 package | Diodes Incorporated | AP2204R-5.0TRG1 | 621-AP2204R-5.0TRG1
U2 | 1 | SN74LV1T34DBV | SN74LV1T34DBV | Package_TO_SOT_SMD:SOT-23-5 | Single Power Supply, Single Buffer GATE, CMOS Logic, Level Shifter, SOT-23-5 | Texas Instruments | SN74LV1T34DBVR | 595-SN74LV1T34DBVR

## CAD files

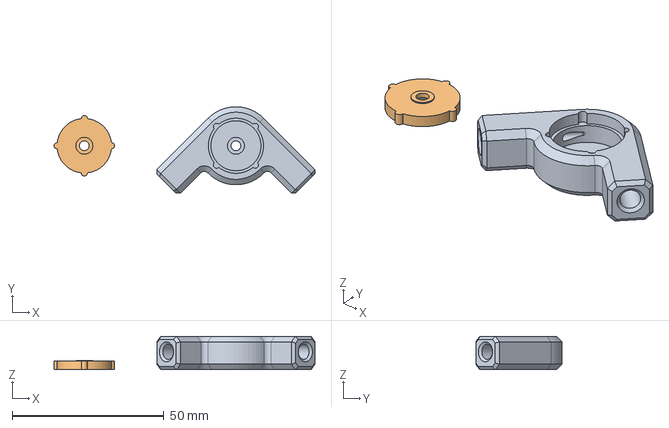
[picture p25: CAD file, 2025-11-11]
Hardware/CAD/Deflection_Pulley/Deflection_Pulley_parametric.FCStd
86.1 x 28.5 x 11.0 mm
Main
Lid

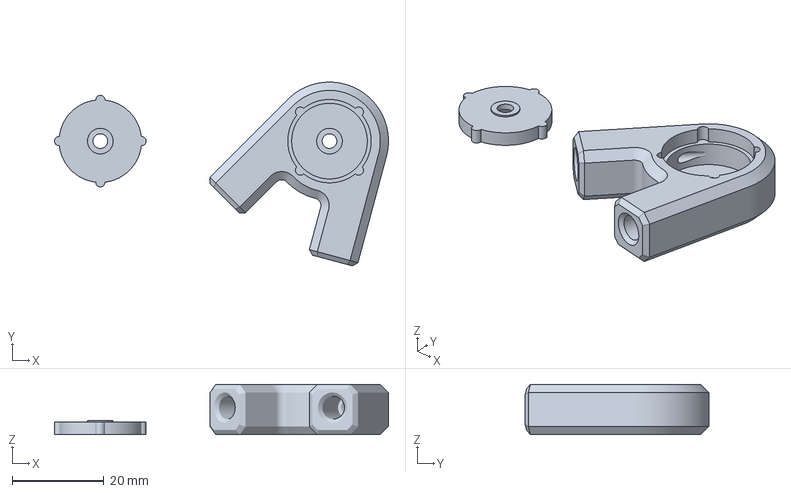
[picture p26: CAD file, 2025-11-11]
Hardware/Printfiles/Deflection_Pulley/Deflection_Pulley_5mm_30Deg_0.16mm.3mf
72.9 x 40.1 x 11.0 mm

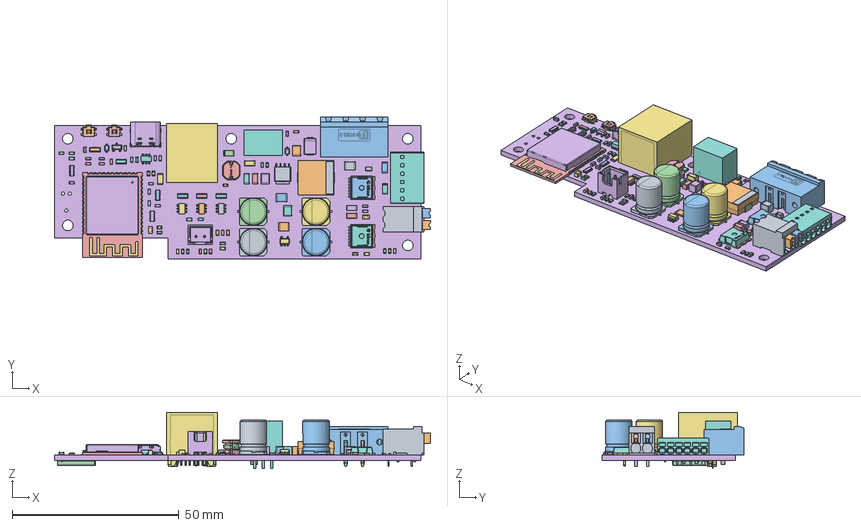
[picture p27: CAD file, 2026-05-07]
Hardware/CAD/BugWiper/BugWiper_Controller_PCB.FCStd
112.8 x 42.5 x 16.8 mm
C_0603_1608Metric
C_0603_1608Metric002
R_0603_1608Metric
R_0603_1608Metric002
R_0603_1608Metric004
D_SMB
R_1206_3216Metric
C_1206_3216Metric
C_1210_3225Metric
C_0603_1608Metric004
D_SOD_323
C_0603_1608Metric006
C_0603_1608Metric008
C_0603_1608Metric010
SOT_23_5
ptsm_0.5-6-2.5-h
DE_BLF7xx-180-HP
DE_BLF7xx-180-HP001
DE_BLF7xx-180-HP002
DE_BLF7xx-180-HP003
DE_BLF7xx-180-HP004
DE_BLF7xx-180-HP005
DE_BLF7xx-180-HP006
R_0603_1608Metric006
C_0603_1608Metric012
R_0603_1608Metric008
R_1206_3216Metric002
C_0603_1608Metric014
R_0603_1608Metric010
R_0603_1608Metric012
R_0603_1608Metric014
R_1210_3225Metric
CP_Elec_8x105
R_0603_1608Metric016
ESP32-S3-WROOM-1_20211021
ESP32-S3-WROOM-1_20211022
ESP32-S3-WROOM-1_20211023
ESP32-S3-WROOM-1_20211024
ESP32-S3-WROOM-1_20211025
ESP32-S3-WROOM-1_20211026
ESP32-S3-WROOM-1_20211027
ESP32-S3-WROOM-1_20211028
ESP32-S3-WROOM-1_20211029
ESP32-S3-WROOM-1_20211030
ESP32-S3-WROOM-1_20211031
ESP32-S3-WROOM-1_20211032
ESP32-S3-WROOM-1_20211033
ESP32-S3-WROOM-1_20211034
ESP32-S3-WROOM-1_20211035
ESP32-S3-WROOM-1_20211036
ESP32-S3-WROOM-1_20211037
ESP32-S3-WROOM-1_20211038
ESP32-S3-WROOM-1_20211039
ESP32-S3-WROOM-1_20211040
ESP32-S3-WROOM-1_20211041
ESP32-S3-WROOM-1_20211042
ESP32-S3-WROOM-1_20211043
ESP32-S3-WROOM-1_20211044
ESP32-S3-WROOM-1_20211045
ESP32-S3-WROOM-1_20211046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

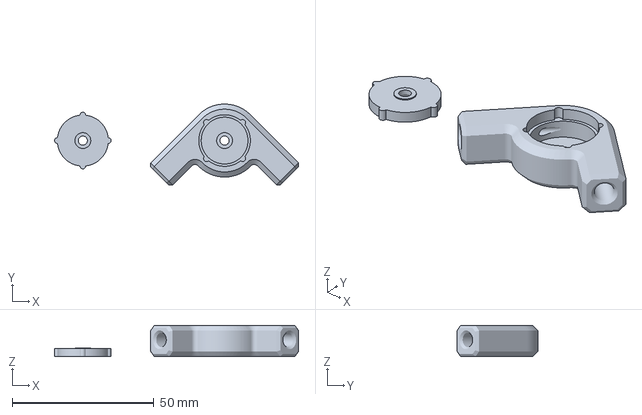
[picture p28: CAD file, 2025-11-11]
Hardware/Printfiles/Deflection_Pulley/Deflection_Pulley_5mm_90Deg_0.16mm.3mf
86.1 x 28.5 x 11.0 mm

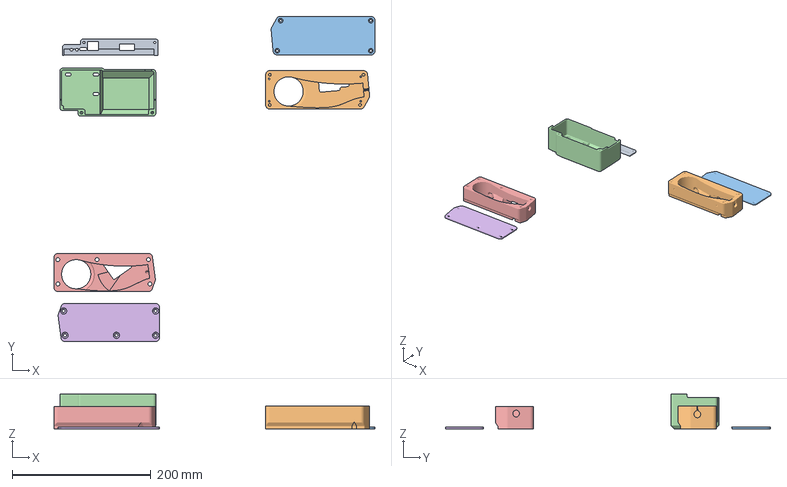
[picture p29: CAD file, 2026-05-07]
Hardware/Printfiles/Housing/BugWiperSystem_Bambu.3mf
462.1 x 468.1 x 50.0 mm
Connector_Cover_V2.stl
Spool_Housing_V2.stl
Spool_Housing_V2_cover.stl
Motor_Housing_V2.stl
Spool_Housing_V1.stl
Spool_Housing_V1_cover.stl

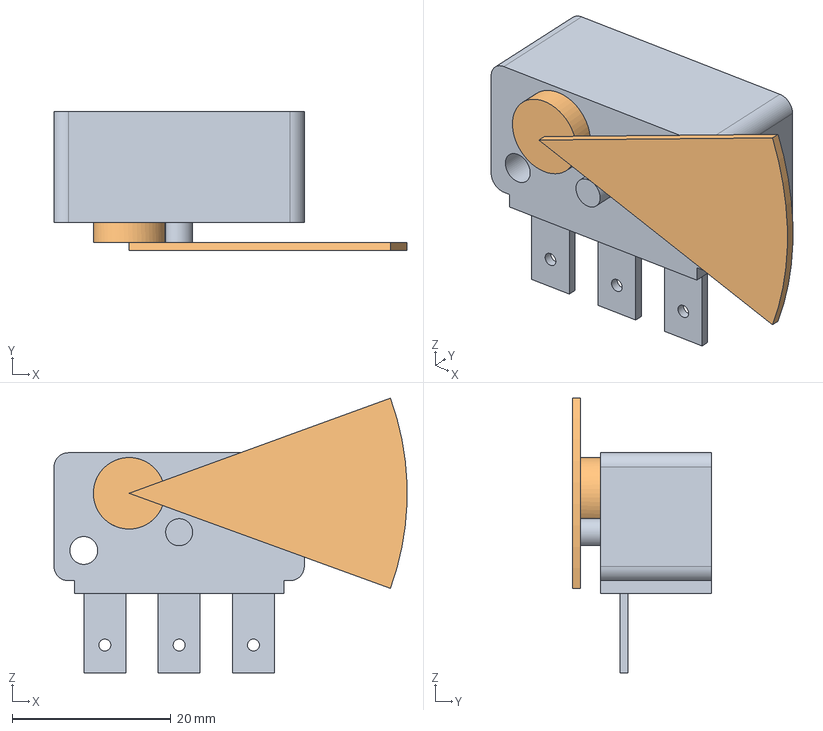
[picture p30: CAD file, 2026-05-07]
Hardware/CAD/BugWiper/Coin_Switch.FCStd
44.4 x 17.5 x 34.6 mm
Coin_Switch_Body
Coin_Switch_Actuator_range

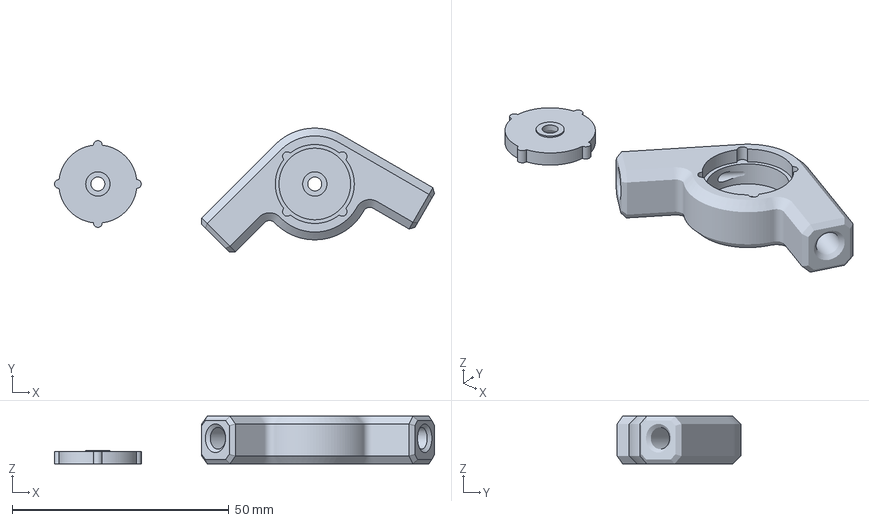
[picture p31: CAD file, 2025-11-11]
Hardware/Printfiles/Deflection_Pulley/Deflection_Pulley_5mm_105Deg_0.16mm.3mf
87.6 x 28.5 x 11.0 mm

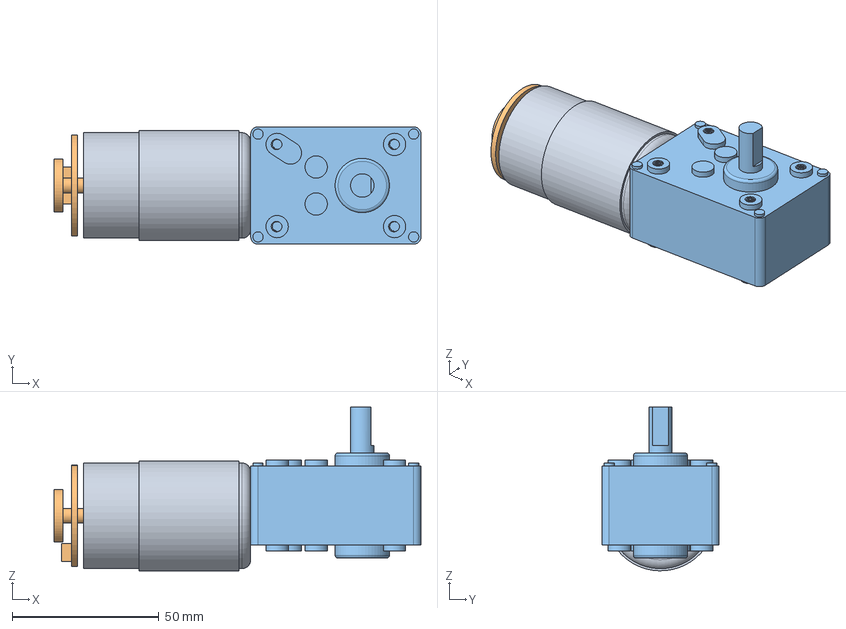
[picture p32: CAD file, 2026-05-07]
Hardware/CAD/BugWiper/5840_geared_motor.FCStd
125.0 x 40.0 x 55.7 mm
Motor001
Encoder
Gear001

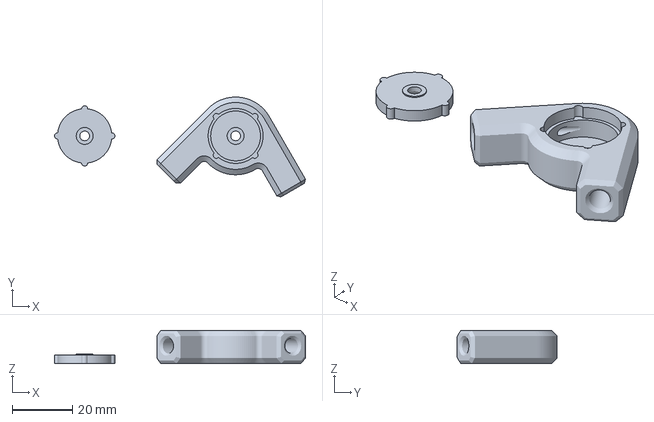
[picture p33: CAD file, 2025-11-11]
Hardware/Printfiles/Deflection_Pulley/Deflection_Pulley_5mm_75Deg_0.16mm.3mf
83.1 x 33.1 x 11.0 mm

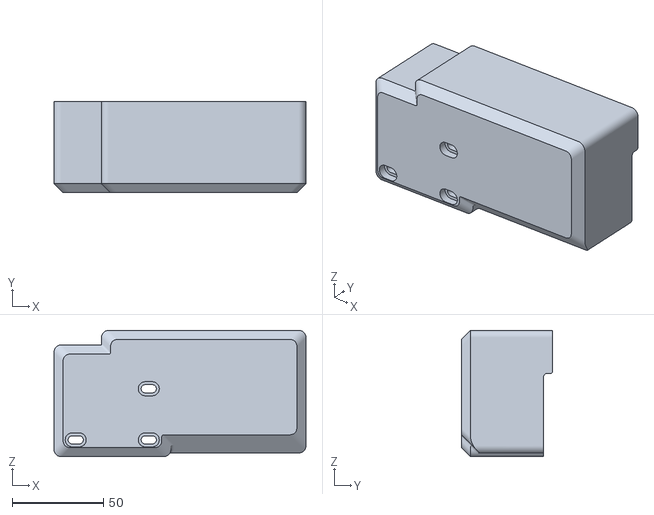
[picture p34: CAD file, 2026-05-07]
Hardware/Printfiles/Housing/Motor_Housing_V2.stl
138.0 x 50.0 x 69.2

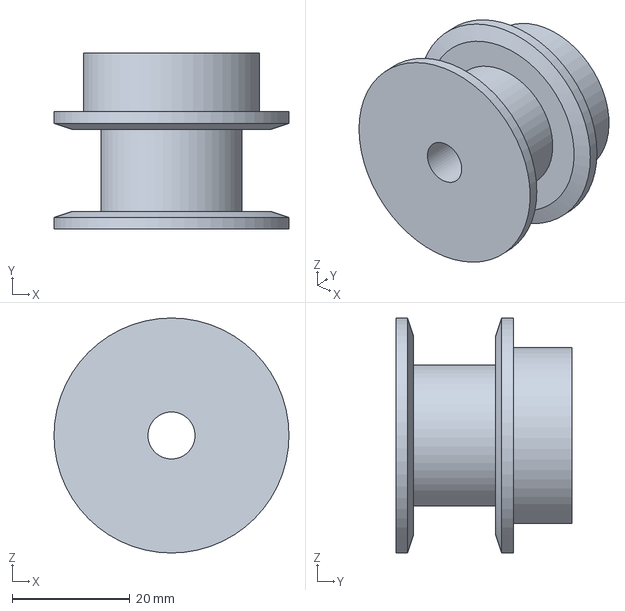
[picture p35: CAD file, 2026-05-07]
Hardware/CAD/BugWiper/Spool_40_8.FCStd
40.0 x 30.0 x 40.0 mm

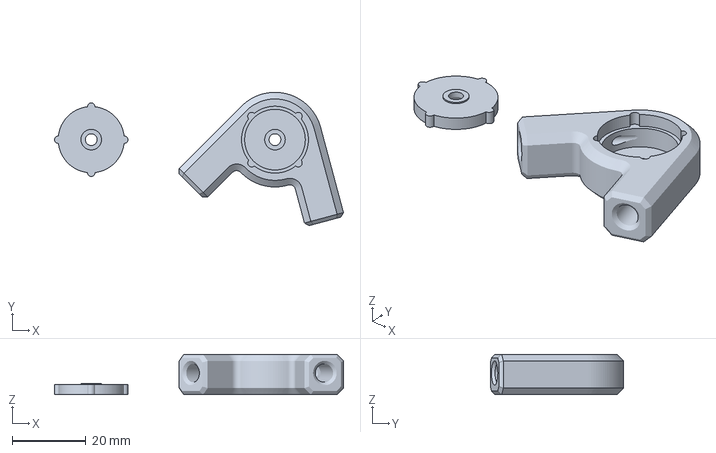
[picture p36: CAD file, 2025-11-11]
Hardware/Printfiles/Deflection_Pulley/Deflection_Pulley_5mm_60Deg_0.16mm.3mf
78.6 x 36.3 x 11.0 mm

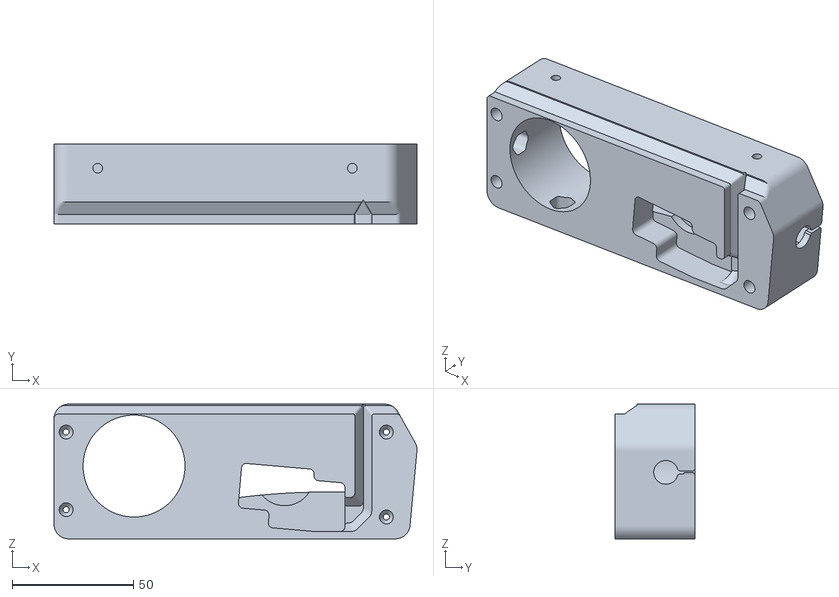
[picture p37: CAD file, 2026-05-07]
Hardware/Printfiles/Housing/Spool_Housing_V2.stl
149.6 x 33.0 x 55.5

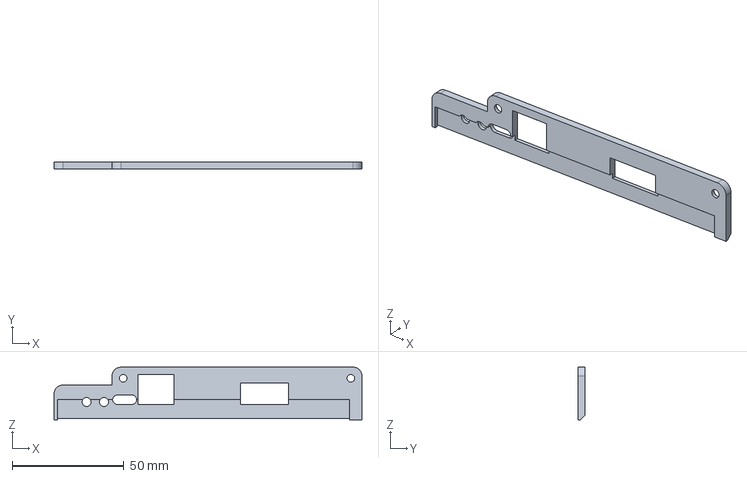
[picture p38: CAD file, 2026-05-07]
Hardware/CAD/BugWiper/Connector_cover_2.FCStd
138.0 x 3.00 x 23.6 mm

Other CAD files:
Hardware/CAD/BugWiper/BugWiperSystem.FCStd
Hardware/Printfiles/Deflection_Pulley/Deflection_Pulley_5mm_120Deg_0.16mm.3mf
Hardware/Printfiles/Housing/Spool_Housing_V2_cover.stl
Hardware/CAD/BugWiper/Coin_Switch_2.FCStd
Hardware/CAD/BugWiper/Connector_cover.FCStd
Hardware/CAD/BugWiper/Housing.FCStd
Hardware/CAD/BugWiper/Motor_housing.FCStd
Hardware/CAD/BugWiper/Motor_housing_2.FCStd
Hardware/CAD/BugWiper/Motor_mount.FCStd
Hardware/CAD/BugWiper/PCB_holder.FCStd
Hardware/CAD/BugWiper/Rigid_Flange_6mm.FCStd
Hardware/CAD/BugWiper/Spool_38mm.FCStd
Hardware/CAD/BugWiper/Spool_45mm.FCStd
Hardware/CAD/BugWiper/Spool_housing.FCStd
Hardware/CAD/BugWiper/Spool_housing_2.FCStd
Hardware/Printfiles/Deflection_Pulley/Deflection_Pulley_5mm_105Deg.stl
Hardware/Printfiles/Deflection_Pulley/Deflection_Pulley_5mm_120Deg.stl
Hardware/Printfiles/Deflection_Pulley/Deflection_Pulley_5mm_30Deg.stl
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

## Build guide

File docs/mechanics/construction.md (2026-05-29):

# Mechanical Construction

## Construction
- CAD in FreeCAD
- FDM 3D Printed Housings
- Aluminium L-Profiles
    - No CNC requiert.
    - everything can be done with a drill, file and handsaw.

## Bill of Material
- 40x40x3mm  Aluminum L-Profile
- 50x50x3mm Aluminum L-Profile
- 12V DC 200rpm High Torque Geared Electric Motor: https://www.amazon.de/gp/product/B00T48KC1Q 
- Micro Switch / Flipper Coin Counter: https://www.amazon.de/dp/B00X5LQMMQ
- to make the cable drum:
CHANCS Aluminium Alloy Double V-Groove Belt Pulley 40 mm OD 8 mm Fixed Pulley for Motor Shaft Bore 6 mm: https://www.amazon.de/gp/product/B0CRR4KS3J

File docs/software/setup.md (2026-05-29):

# Software Setup
The software of the BugWiper2.0 is written in C++ and runs on an ESP32S3 microcontroller. The software is developed using the Arduino IDE 2.3.8 and uses the following libraries:
- ESP32Encoder 0.12.0 by Kevin Harrington: https://github.com/madhephaestus/ESP32Encoder    
- Manual Installed arduino-motix-btn99x0 from: https://github.com/M-Scholli/arduino-motix-btn99x0/tree/add_ESP32_support

In the Arduino IDE, the ESP32 board support package by Espressif Systems version 3.3.8 is used. The selected board is the ESP32S3 DEV Module.

Select the correct COM port in the Arduino IDE under Tools and configure the board settings as shown in the following image:
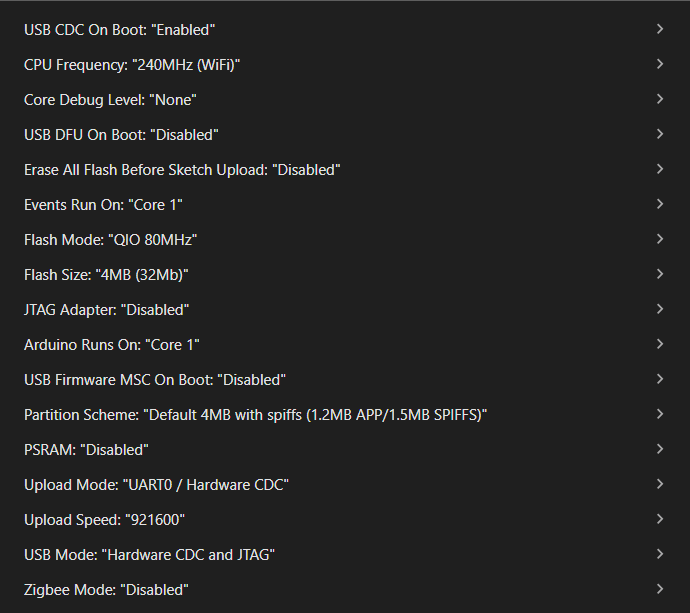
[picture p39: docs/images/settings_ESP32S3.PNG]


For Development and testing the Core Debug Level "Info" is used. For the final version, the Core Debug Level "None" will be used to reduce the amount of debug messages and save some processing power of the ESP32S3.

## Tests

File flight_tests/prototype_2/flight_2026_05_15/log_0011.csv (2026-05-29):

time | state | position | speed | motor current in mA | BatteryVoltage | NTC temp in C | Cable Loose | event
1531 | IDLE | 0 | 0 | 0 | 13.0 | 4.9 | false | -
2930 | IDLE | 0 | 0 | 0 | 13.0 | 4.9 | false | FSM Transition: IDLE -> START_CLEAN_OUT
3056 | START_CLEAN_OUT | 4 | 10 | 515 | 12.8 | 4.9 | false | -
3561 | START_CLEAN_OUT | 56 | 20 | 125 | 12.9 | 4.9 | false | -
3830 | START_CLEAN_OUT | 98 | 25 | 15 | 13.0 | 4.8 | true | FSM Transition: START_CLEAN_OUT -> DECEL_LOOSE
3870 | DECEL_LOOSE | 102 | 9 | 10 | 13.0 | 4.9 | false | FSM Transition: DECEL_LOOSE -> START_CLEAN_OUT
3990 | START_CLEAN_OUT | 109 | 10 | 450 | 12.8 | 4.9 | true | FSM Transition: START_CLEAN_OUT -> DECEL_LOOSE
4067 | DECEL_LOOSE | 112 | 1 | 0 | 12.9 | 4.9 | true | -
4090 | DECEL_LOOSE | 112 | 0 | 0 | 13.0 | 4.9 | false | FSM Transition: DECEL_LOOSE -> START_CLEAN_OUT
4350 | START_CLEAN_OUT | 130 | 13 | 360 | 12.9 | 4.9 | true | FSM Transition: START_CLEAN_OUT -> DECEL_LOOSE
4490 | DECEL_LOOSE | 132 | 0 | 0 | 13.0 | 4.9 | false | FSM Transition: DECEL_LOOSE -> START_CLEAN_OUT
4572 | START_CLEAN_OUT | 136 | 11 | 605 | 12.9 | 4.9 | false | -
5077 | START_CLEAN_OUT | 187 | 22 | 120 | 12.9 | 4.9 | false | -
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

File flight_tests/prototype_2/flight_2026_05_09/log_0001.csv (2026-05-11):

time | state | position | speed | motor_current | BatteryVoltage_filtered
5750 | IDLE | 0 | 0 | 0.00 | 1609.0
5768 | IDLE | 0 | 0 | 0.00 | 13.0
13848 | START_CLEAN_OUT | 0 | 0 | 0.00 | 13.0
14274 | START_CLEAN_OUT | 29 | 19 | 890.00 | 12.7
14780 | START_CLEAN_OUT | 104 | 28 | 540.00 | 12.8
15228 | CLEANING | 202 | 35 | 465.00 | 12.8
15286 | CLEANING | 212 | 38 | 355.00 | 12.8
15791 | CLEANING | 376 | 59 | 160.00 | 12.8
16297 | CLEANING | 599 | 79 | 680.00 | 12.7
16803 | CLEANING | 853 | 75 | 880.00 | 12.7
17309 | CLEANING | 1115 | 81 | 605.00 | 12.7
17815 | CLEANING | 1369 | 78 | 735.00 | 12.8
18321 | CLEANING | 1625 | 78 | 525.00 | 12.8
18827 | CLEANING | 1878 | 76 | 825.00 | 12.7
19335 | CLEANING | 2141 | 77 | 625.00 | 12.8
19841 | CLEANING | 2398 | 81 | 505.00 | 12.8
20347 | CLEANING | 2655 | 79 | 650.00 | 12.8
20853 | CLEANING | 2924 | 78 | 595.00 | 12.8
21359 | CLEANING | 3183 | 80 | 555.00 | 12.8
21865 | CLEANING | 3440 | 75 | 840.00 | 12.8
22371 | CLEANING | 3707 | 79 | 655.00 | 12.7
22877 | CLEANING | 3965 | 79 | 615.00 | 12.8
23383 | CLEANING | 4225 | 78 | 655.00 | 12.8
23889 | CLEANING | 4493 | 81 | 500.00 | 12.8
24395 | CLEANING | 4751 | 78 | 740.00 | 12.8
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

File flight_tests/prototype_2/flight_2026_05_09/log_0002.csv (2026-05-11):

time | state | position | speed | motor_current | BatteryVoltage_filtered
5858 | IDLE | 0 | 0 | 0.00 | 1624.0
5876 | IDLE | 0 | 0 | 0.00 | 13.2
10696 | WINDING_IN | 0 | 0 | 0.00 | 13.2
10882 | WINDING_IN | -7 | -10 | 2125.00 | 12.5
11296 | WINDING_IN_DECEL | -84 | -42 | 1745.00 | 12.5
11387 | WINDING_IN_DECEL | -105 | -38 | 1555.00 | 12.6
11892 | WINDING_IN_DECEL | -214 | -32 | 2265.00 | 12.4
12398 | WINDING_IN_DECEL | -302 | -25 | 3355.00 | 12.0
12904 | WINDING_IN_DECEL | -440 | -42 | 1140.00 | 12.7
13410 | WINDING_IN_DECEL | -577 | -47 | 920.00 | 12.7
13916 | WINDING_IN_DECEL | -716 | -28 | 2320.00 | 12.4
14422 | WINDING_IN_DECEL | -728 | 0 | 5985.00 | 11.4
14516 | WINDING_IN_DECEL | -728 | 0 | 5980.00 | 11.4
14521 | FINISHED | -728 | 0 | 6035.00 | 11.4
14536 | IDLE | 0 | 0 | 4725.00 | 11.6
16776 | START_CLEAN_OUT | 0 | 0 | 0.00 | 13.1
16930 | START_CLEAN_OUT | 7 | 14 | 305.00 | 13.1
17435 | START_CLEAN_OUT | 68 | 20 | 1060.00 | 12.8
17876 | DECEL_LOOSE | 150 | 31 | 750.00 | 12.8
17896 | DECEL_LOOSE | 153 | 24 | 495.00 | 12.9
17916 | DECEL_LOOSE | 154 | 8 | 255.00 | 12.9
17936 | DECEL_LOOSE | 154 | 3 | 60.00 | 13.0
17941 | DECEL_LOOSE | 154 | 3 | 0.00 | 13.0
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

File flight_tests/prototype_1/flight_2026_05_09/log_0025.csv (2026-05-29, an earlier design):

time | state | position | speed | motor_current | BatteryVoltage_filtered
2599 | IDLE | 0 | 0 | 0.00 | 1627.0
2617 | IDLE | 0 | 0 | 0.00 | 13.2
38537 | START_CLEAN_OUT | 0 | 0 | 0.00 | 13.2
38627 | START_CLEAN_OUT | 2 | 9 | 115.00 | 13.0
39137 | START_CLEAN_OUT | 59 | 22 | 0.00 | 13.0
39647 | START_CLEAN_OUT | 148 | 33 | 0.00 | 13.0
39877 | CLEANING | 203 | 37 | 0.00 | 13.0
40158 | CLEANING | 280 | 47 | 30.00 | 13.0
40670 | CLEANING | 469 | 67 | 195.00 | 12.9
41185 | CLEANING | 727 | 81 | 500.00 | 12.9
41694 | CLEANING | 989 | 80 | 540.00 | 12.9
42203 | CLEANING | 1261 | 80 | 495.00 | 12.9
42713 | CLEANING | 1524 | 80 | 510.00 | 12.9
43223 | CLEANING | 1797 | 80 | 505.00 | 12.9
43735 | CLEANING | 2060 | 80 | 465.00 | 12.9
44244 | CLEANING | 2334 | 80 | 490.00 | 12.9
44753 | CLEANING | 2597 | 80 | 505.00 | 12.9
45263 | CLEANING | 2871 | 80 | 500.00 | 12.9
45769 | CLEANING | 3134 | 80 | 505.00 | 12.9
46275 | CLEANING | 3397 | 80 | 465.00 | 12.9
46782 | CLEANING | 3670 | 80 | 480.00 | 12.9
47289 | CLEANING | 3933 | 80 | 505.00 | 12.9
47457 | DECEL_LOOSE | 4028 | 81 | 470.00 | 12.9
47477 | DECEL_LOOSE | 4036 | 61 | 340.00 | 12.9
47497 | DECEL_LOOSE | 4040 | 26 | 200.00 | 13.0
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

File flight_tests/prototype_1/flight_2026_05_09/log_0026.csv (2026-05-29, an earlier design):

time | state | position | speed | motor_current | BatteryVoltage_filtered
2677 | IDLE | 0 | 0 | 0.00 | 1629.0
2690 | IDLE | 0 | 0 | 0.00 | 13.2
33370 | START_CLEAN_OUT | 0 | 0 | 0.00 | 13.1
33700 | START_CLEAN_OUT | 14 | 16 | 830.00 | 12.8
34211 | START_CLEAN_OUT | 87 | 27 | 450.00 | 12.9
34723 | START_CLEAN_OUT | 192 | 37 | 150.00 | 13.0
34750 | CLEANING | 202 | 38 | 140.00 | 13.0
35235 | CLEANING | 348 | 55 | 40.00 | 13.0
35748 | CLEANING | 564 | 76 | 510.00 | 12.9
36263 | CLEANING | 834 | 80 | 515.00 | 12.9
36773 | CLEANING | 1106 | 81 | 505.00 | 12.9
37283 | CLEANING | 1369 | 80 | 535.00 | 12.9
37794 | CLEANING | 1642 | 80 | 530.00 | 12.9
38306 | CLEANING | 1905 | 81 | 525.00 | 12.9
38815 | CLEANING | 2179 | 81 | 520.00 | 12.9
39324 | CLEANING | 2443 | 81 | 485.00 | 12.9
39834 | CLEANING | 2717 | 81 | 505.00 | 12.9
40340 | CLEANING | 2981 | 81 | 480.00 | 12.9
40847 | CLEANING | 3245 | 81 | 495.00 | 12.9
41350 | DECEL_LOOSE | 3520 | 80 | 505.00 | 12.9
41358 | DECEL_LOOSE | 3520 | 80 | 455.00 | 12.9
41370 | DECEL_LOOSE | 3528 | 61 | 355.00 | 12.9
41390 | DECEL_LOOSE | 3531 | 26 | 200.00 | 13.0
41410 | DECEL_LOOSE | 3532 | 10 | 45.00 | 13.0
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

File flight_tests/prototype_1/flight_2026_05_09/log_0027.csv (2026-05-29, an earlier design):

time | state | position | speed | motor_current | BatteryVoltage_filtered
2693 | IDLE | 0 | 0 | 0.00 | 1624.0
2708 | IDLE | 0 | 0 | 0.00 | 13.1
7108 | WINDING_IN | 0 | 0 | 0.00 | 13.1
7220 | WINDING_IN | 0 | 0 | 175.00 | 13.0
7733 | WINDING_IN | 0 | 0 | 2840.00 | 12.3
8242 | WINDING_IN | -1 | 0 | 10605.00 | 10.1
8708 | WINDING_IN | -1 | 0 | 10665.00 | 10.1
8718 | FINISHED | -1 | 0 | 10665.00 | 10.1
8729 | IDLE | 0 | 0 | 8680.00 | 10.4
247228 | START_CLEAN_OUT | 0 | 0 | 0.00 | 13.1
247252 | START_CLEAN_OUT | 0 | 0 | 20.00 | 13.1
247764 | START_CLEAN_OUT | 24 | 20 | 15.00 | 13.0
248277 | START_CLEAN_OUT | 111 | 31 | 35.00 | 13.0
248668 | CLEANING | 201 | 39 | 80.00 | 13.0
248786 | CLEANING | 228 | 42 | 110.00 | 13.0
249293 | CLEANING | 406 | 62 | 355.00 | 12.9
249801 | CLEANING | 643 | 80 | 570.00 | 12.8
250310 | CLEANING | 914 | 80 | 570.00 | 12.8
250819 | CLEANING | 1176 | 80 | 545.00 | 12.8
251330 | CLEANING | 1449 | 80 | 545.00 | 12.8
251836 | CLEANING | 1711 | 80 | 545.00 | 12.8
252342 | CLEANING | 1974 | 81 | 545.00 | 12.8
252849 | CLEANING | 2248 | 80 | 530.00 | 12.8
253360 | CLEANING | 2511 | 80 | 500.00 | 12.9
253548 | DECEL_LOOSE | 2616 | 80 | 540.00 | 12.8
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

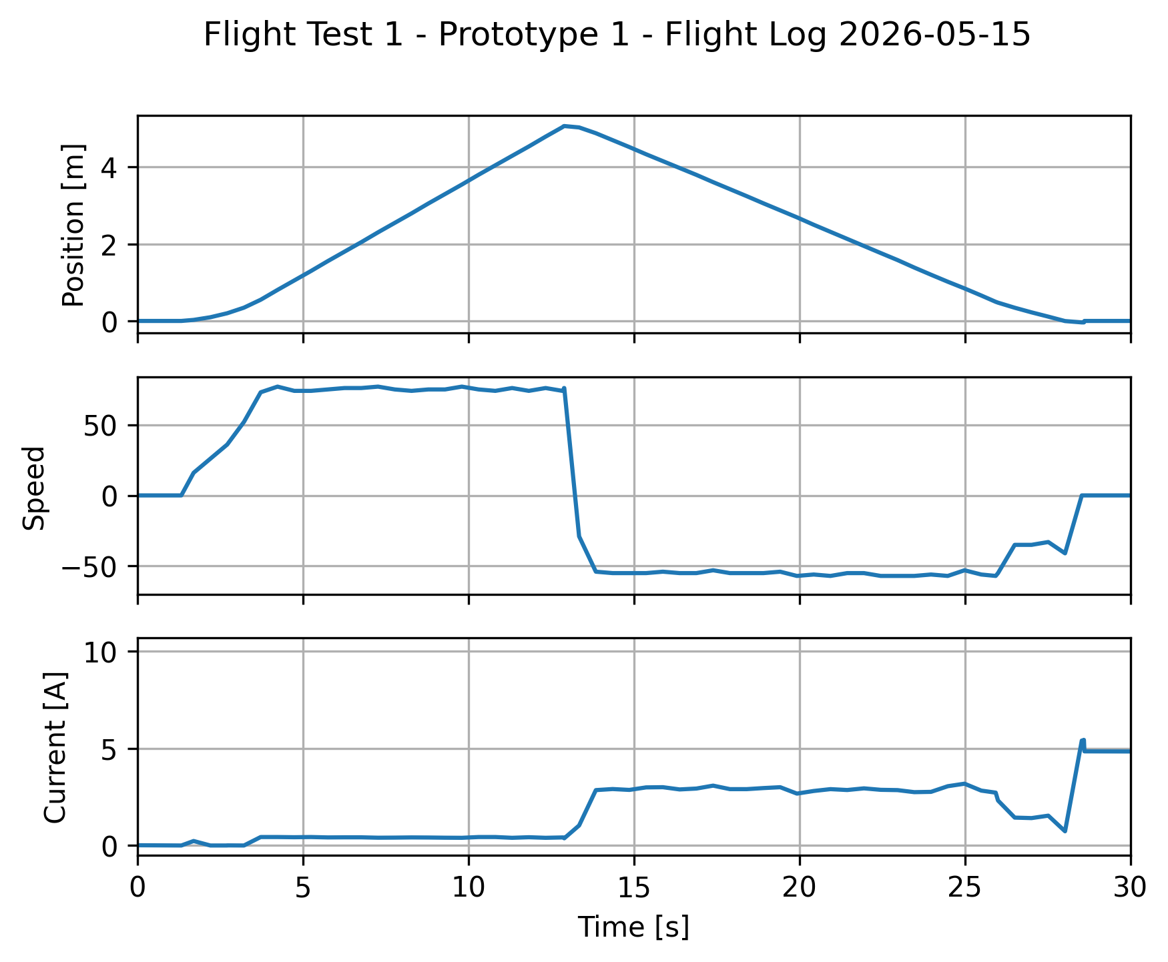
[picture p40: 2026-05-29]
flight_tests/plots/prototype_2/flight_2026_05_15/log_0011_flight_test_1.png

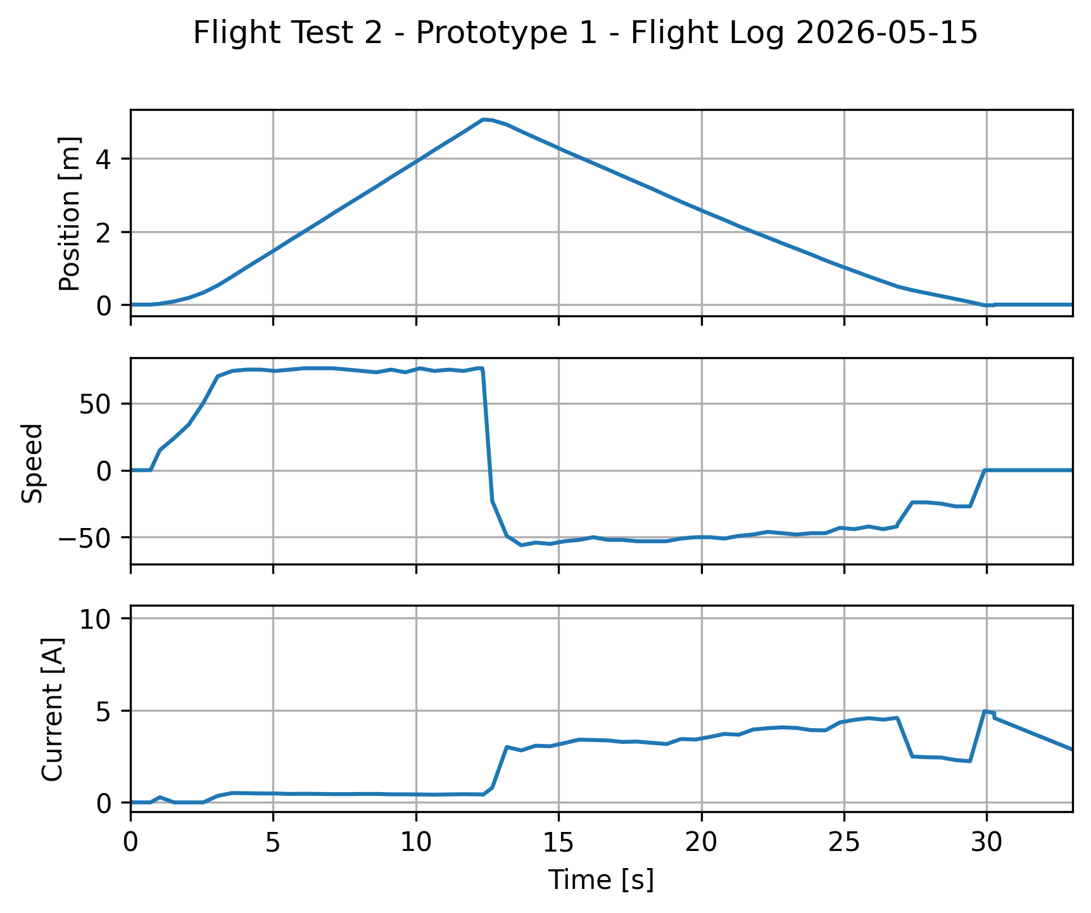
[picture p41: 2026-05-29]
flight_tests/plots/prototype_2/flight_2026_05_15/log_0011_flight_test_2.png

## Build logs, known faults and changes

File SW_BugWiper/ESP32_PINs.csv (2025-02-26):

EN;;reset button;
GPIO36;MOTOR_CURRENT_SENSE_PIN;input only;no pull-up or pull-down
GPIO39;MOTOR_B_CURRENT_SENSE_PIN;input only;no pull-up or pull-down
GPIO34;MOTOR_B_ENCODER_1_PIN;input only;no pull-up or pull-down
GPIO35;MOTOR_B_ENCODER_2_PIN;input only;no pull-up or pull-down
GPIO32;MOTOR_ENCODER_1_PIN;
GPIO33;MOTOR_ENCODER_1_PIN;
GPIO25;MOTOR_B_EN_PIN;
GPIO26;MOTOR_B_IN1_PIN;
GPIO27;MOTOR_B_IN2_PIN;
GPIO14;MOTOR_EN_PIN;;;;Sends a PWM signal at boot time
GPIO12;MOTOR_IN1_PIN;Strapping PIN;MTDI;pull-down
GPIO13;MOTOR_IN2_PIN;
GND;
VIN;
GPIO23;SW_CABLE_LOOSE_A_PIN
GPIO22;SW_CABLE_LOOSE_B_PIN
GPIO1;UART 0 TX;;;;Sends the ESP32 boot logs via the UART
GPIO3;UART o RX;;;; 3.3V voltage at boot time
GPIO21;BUTTON_CLEANING_A_PIN;
GPIO19;BUTTON_CLEANING_B_PIN;
GPIO18;BUTTON_WINDING_IN_A_PIN;
GPIO5;;Strapping PIN;;pull-up;Sends a PWM signal at boot time
GPIO17;BUTTON_WINDING_IN_B_PIN;;(internal PSRAM);
GPIO16;Safty_Switch;;(internal PSRAM);
GPIO4;(Landing Gear Sensor);
GPIO2;STATUS_LED_A;BOARD LED;Strapping PIN;Boot_Mode 1.8V;pull-dowm
GPIO15;(STATUS_LED_B);Strapping PIN;MTDO;pull-up;Sends the ESP32 boot logs via the UART
GND;
3V3;

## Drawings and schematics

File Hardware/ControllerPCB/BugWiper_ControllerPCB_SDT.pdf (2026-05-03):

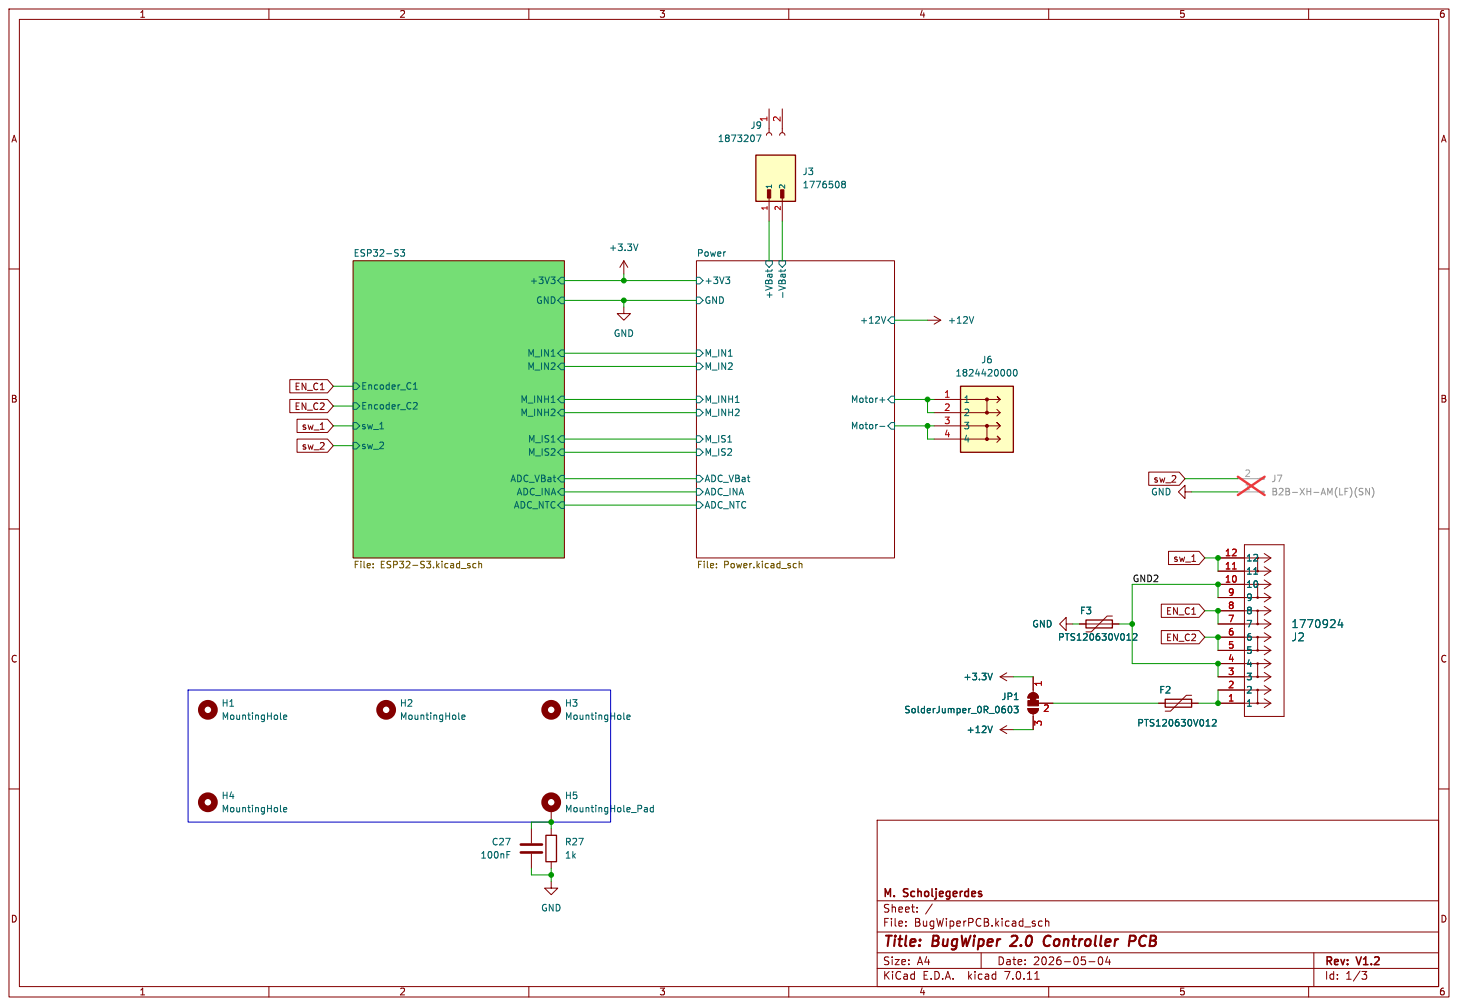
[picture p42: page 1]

Power File: Power.kicad_sch H4 MountingHole

J7B2B-XH-AM(LF)(SN) F2 PTS120630V012 F3 PTS120630V012 EN_C2

File: BugWiperPCB.kicad_sch Sheet: / M. Scholjegerdes

Id: 1/3 Title: BugWiper 2.0 Controller PCB

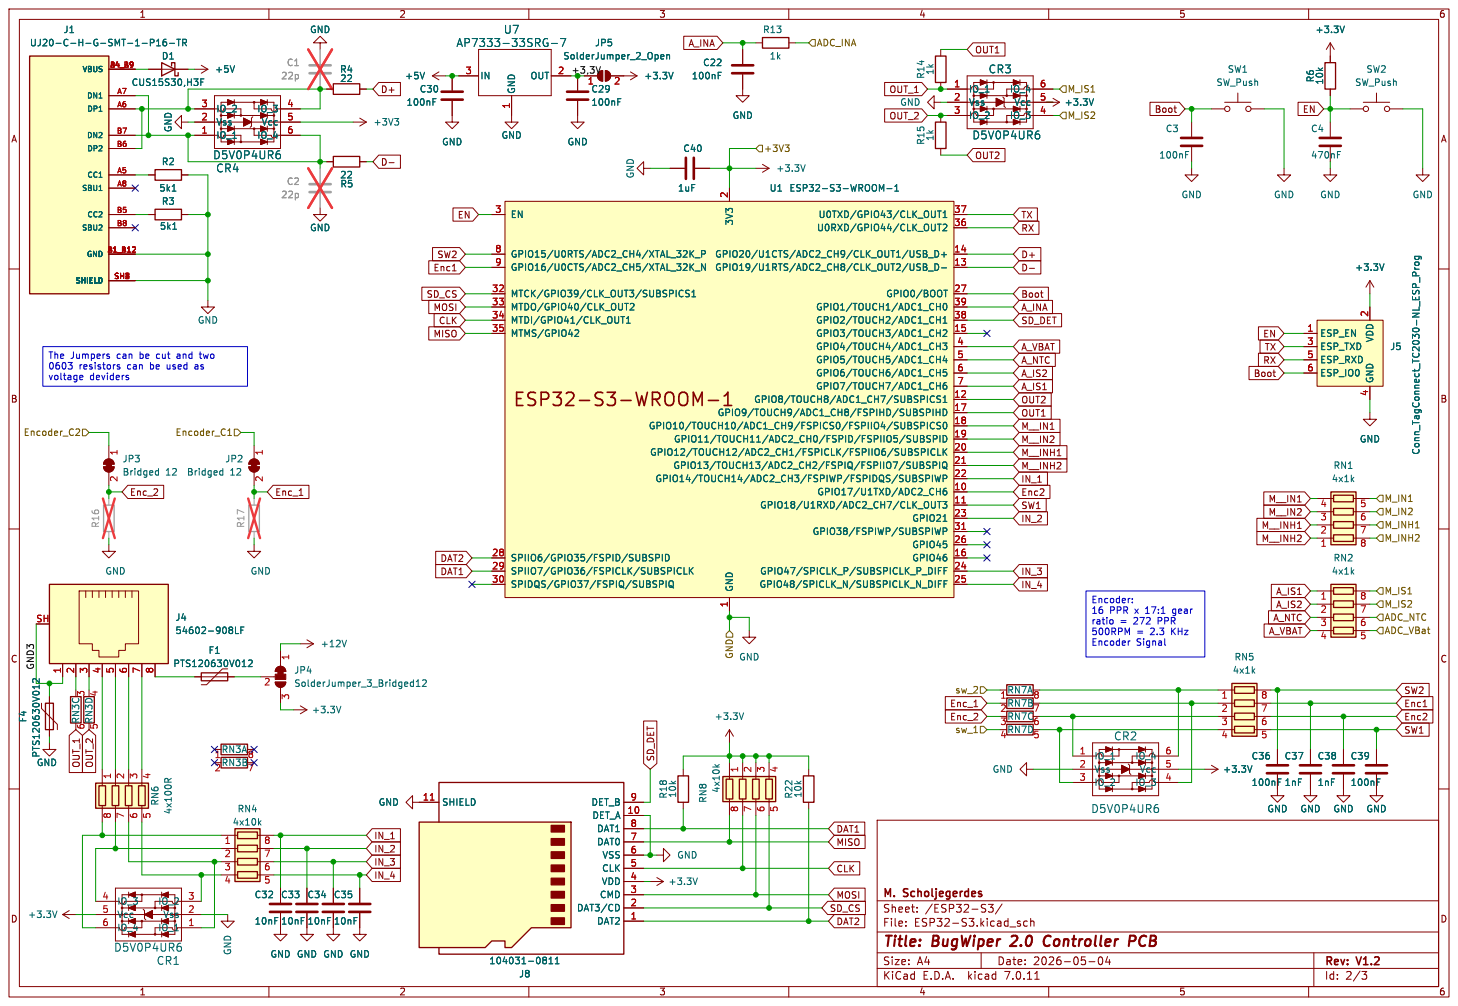
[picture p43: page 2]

2 GPIO12/TOUCH12/ADC2_CH1/FSPICLK/FSPIIO6/SUBSPICLK 20 GPIO13/TOUCH13/ADC2_CH2/FSPIQ/FSPIIO7/SUBSPIQ 21 GPIO14/TOUCH14/ADC2_CH3/FSPIWP/FSPIDQS/SUBSPIWP 22 GPIO21 23 GPIO47/SPICLK_P/SUBSPICLK_P_DIFF 24 GPIO48/SPICLK_N/SUBSPICLK_N_DIFF 25 GPIO45 26 GPIO0/BOOT 27 SPIIO6/GPIO35/FSPID/SUBSPID 28 SPIIO7/GPIO36/FSPICLK/SUBSPICLK 29 EN 3 SPIDQS/GPIO37/FSPIQ/SUBSPIQ 30 GPIO38/FSPIWP/SUBSPIWP 31 MTCK/GPIO39/CLK_OUT3/SUBSPICS1 32 MTDO/GPIO40/CLK_OUT2 33 MTDI/GPIO41/CLK_OUT1 34 MTMS/GPIO42 35 U0RXD/GPIO44/CLK_OUT2 36 U0TXD/GPIO43/CLK_OUT1 37 GPIO2/TOUCH2/ADC1_CH1 38 GPIO1/TOUCH1/ADC1_CH0 39 GPIO4/TOUCH4/ADC1_CH3 4 GPIO5/TOUCH5/ADC1_CH4 5 GPIO6/TOUCH6/ADC1_CH5 6 GPIO7/TOUCH7/ADC1_CH6 7 GPIO15/U0RTS/ADC2_CH4/XTAL_32K_P 8 GPIO16/U0CTS/ADC2_CH5/XTAL_32K_N 9 U1 ESP32-S3-WROOM-1 +3.3V C22

2 GPIO12/TOUCH12/ADC2_CH1/FSPICLK/FSPIIO6/SUBSPICLK 20 GPIO13/TOUCH13/ADC2_CH2/FSPIQ/FSPIIO7/SUBSPIQ 21 GPIO14/TOUCH14/ADC2_CH3/FSPIWP/FSPIDQS/SUBSPIWP 22 GPIO21 23 GPIO47/SPICLK_P/SUBSPICLK_P_DIFF 24 GPIO48/SPICLK_N/SUBSPICLK_N_DIFF 25 GPIO45 26 GPIO0/BOOT 27 SPIIO6/GPIO35/FSPID/SUBSPID 28 SPIIO7/GPIO36/FSPICLK/SUBSPICLK 29 EN 3 SPIDQS/GPIO37/FSPIQ/SUBSPIQ 30 GPIO38/FSPIWP/SUBSPIWP 31 MTCK/GPIO39/CLK_OUT3/SUBSPICS1 32 MTDO/GPIO40/CLK_OUT2 33 MTDI/GPIO41/CLK_OUT1 34 MTMS/GPIO42 35 U0RXD/GPIO44/CLK_OUT2 36 U0TXD/GPIO43/CLK_OUT1 37 GPIO2/TOUCH2/ADC1_CH1 38 GPIO1/TOUCH1/ADC1_CH0 39 GPIO4/TOUCH4/ADC1_CH3 4 GPIO5/TOUCH5/ADC1_CH4 5 GPIO6/TOUCH6/ADC1_CH5 6 GPIO7/TOUCH7/ADC1_CH6 7 GPIO15/U0RTS/ADC2_CH4/XTAL_32K_P 8 GPIO16/U0CTS/ADC2_CH5/XTAL_32K_N 9 C22

1 GPIO17/U1TXD/ADC2_CH6 10 GPIO18/U1RXD/ADC2_CH7/CLK_OUT3 11 GPIO8/TOUCH8/ADC1_CH7/SUBSPICS1 12 GPIO19/U1RTS/ADC2_CH8/CLK_OUT2/USB_D- 13 GPIO20/U1CTS/ADC2_CH9/CLK_OUT1/USB_D+ 14 GPIO3/TOUCH3/ADC1_CH2 15 GPIO46 16 GPIO9/TOUCH9/ADC1_CH8/FSPIHD/SUBSPIHD 17 GPIO10/TOUCH10/ADC1_CH9/FSPICS0/FSPIIO4/SUBSPICS0 18 GPIO11/TOUCH11/ADC2_CH0/FSPID/FSPIIO5/SUBSPID 19 3V3

Id: 2/3 Title: BugWiper 2.0 Controller PCB

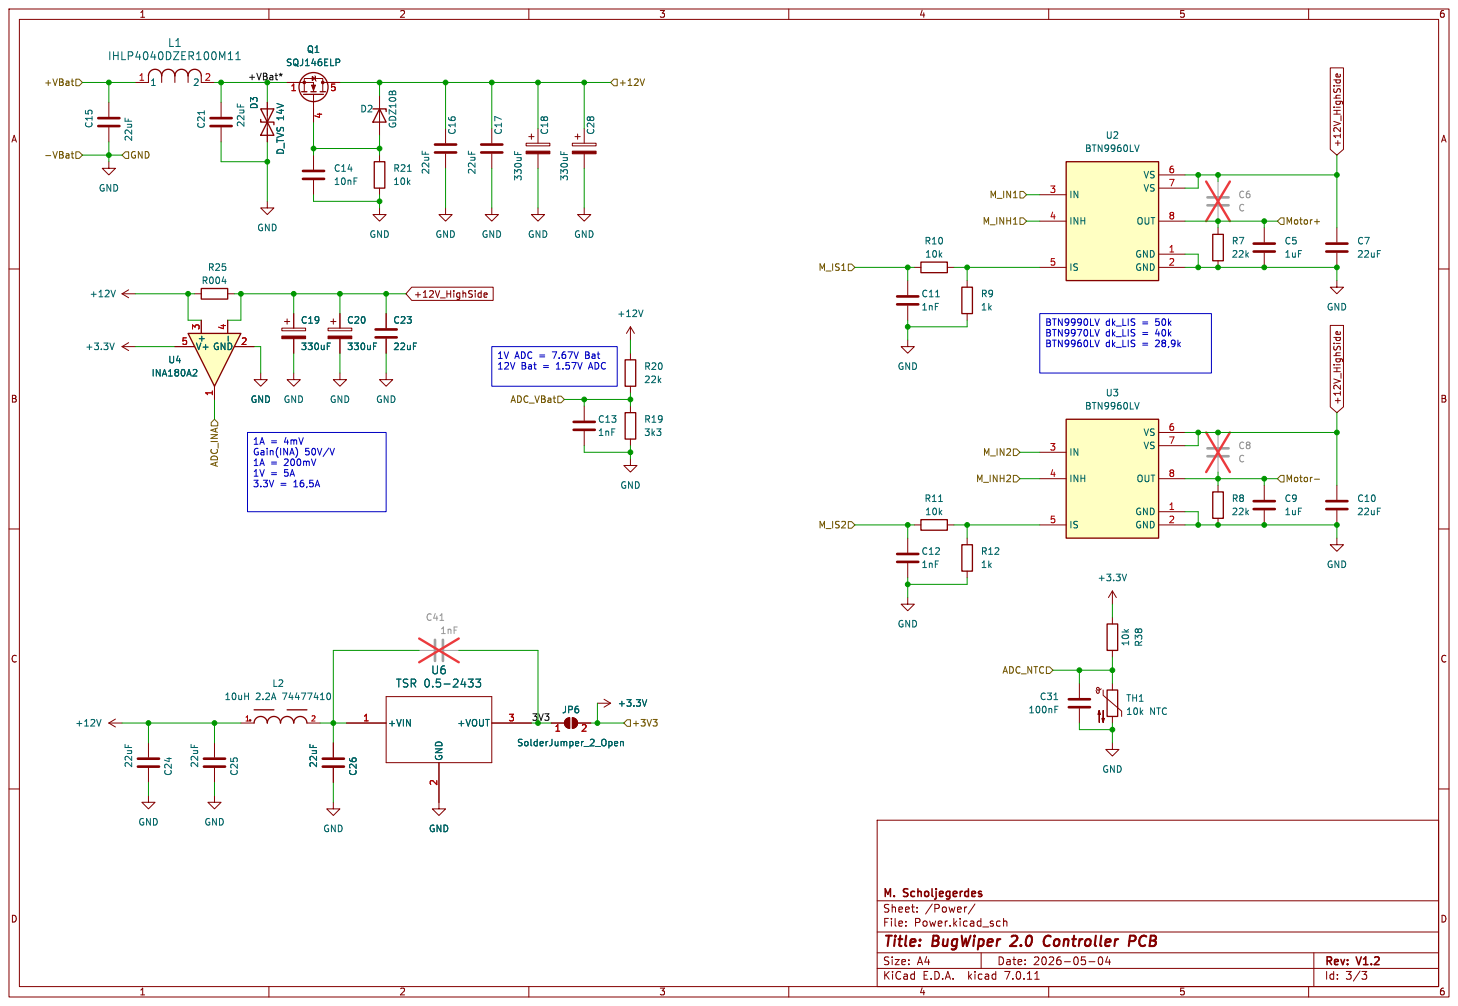
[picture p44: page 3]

1V ADC = 7.67V Bat 12V Bat = 1.57V ADC

File: Power.kicad_sch Sheet: /Power/ M. Scholjegerdes

Id: 3/3 Title: BugWiper 2.0 Controller PCB

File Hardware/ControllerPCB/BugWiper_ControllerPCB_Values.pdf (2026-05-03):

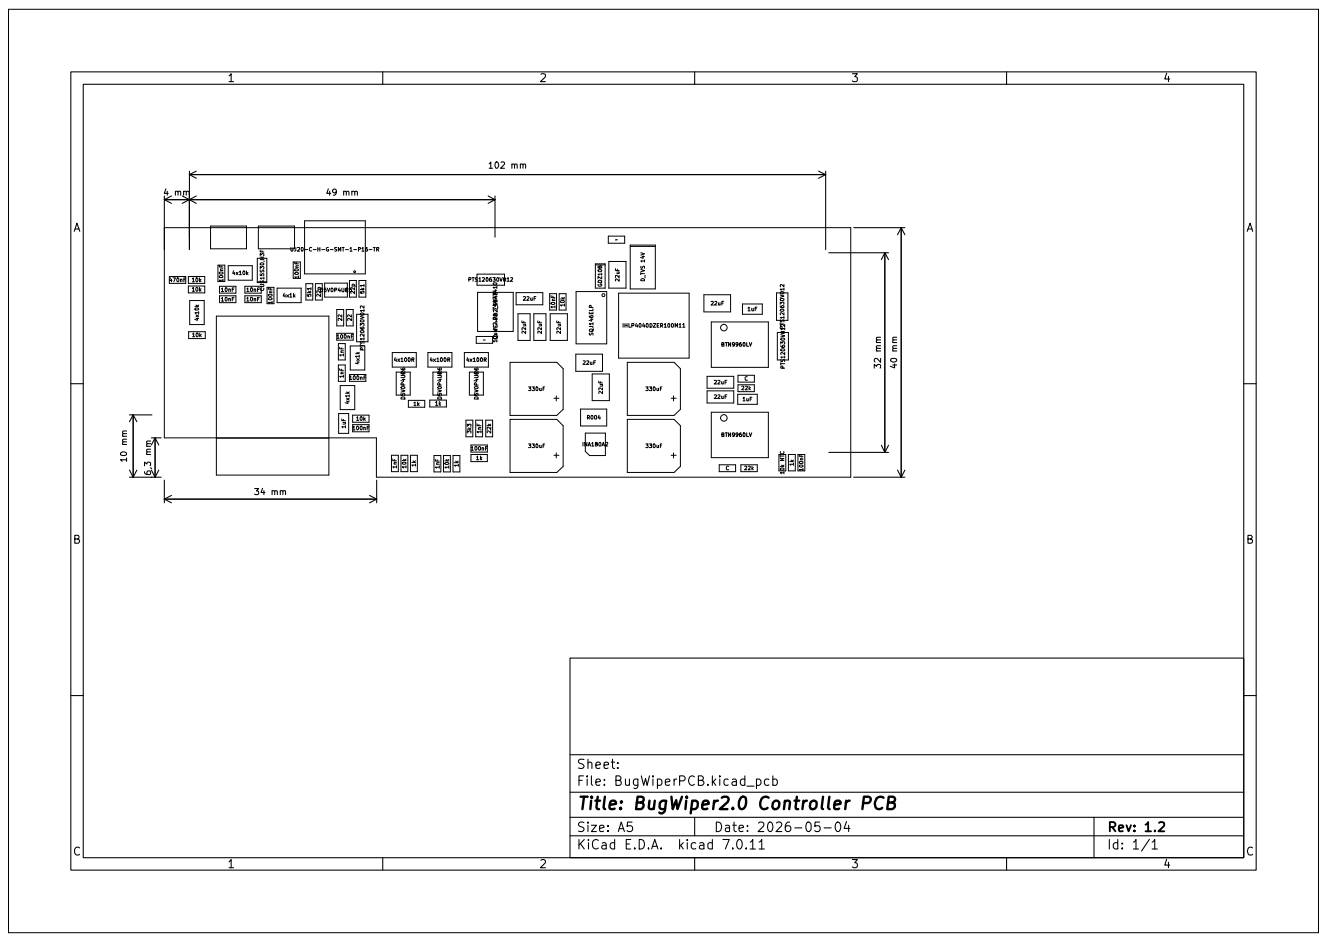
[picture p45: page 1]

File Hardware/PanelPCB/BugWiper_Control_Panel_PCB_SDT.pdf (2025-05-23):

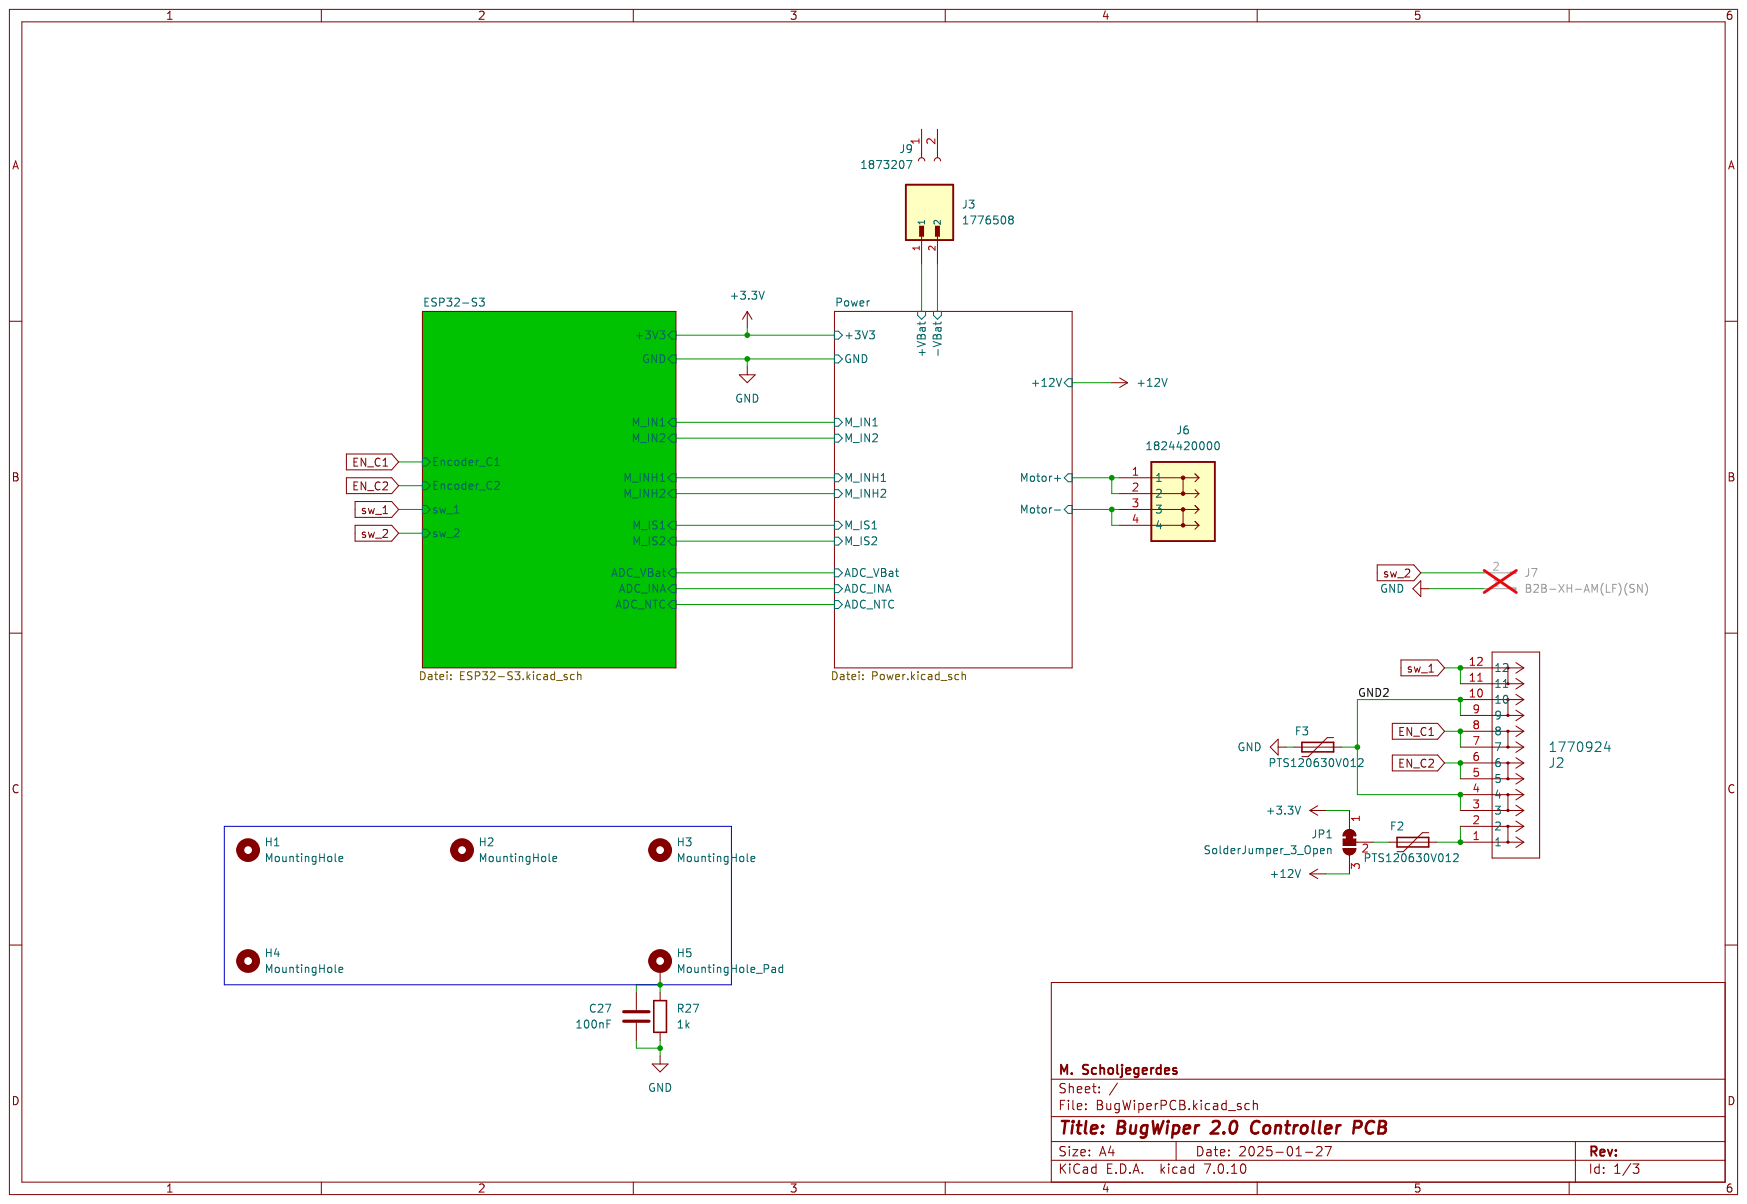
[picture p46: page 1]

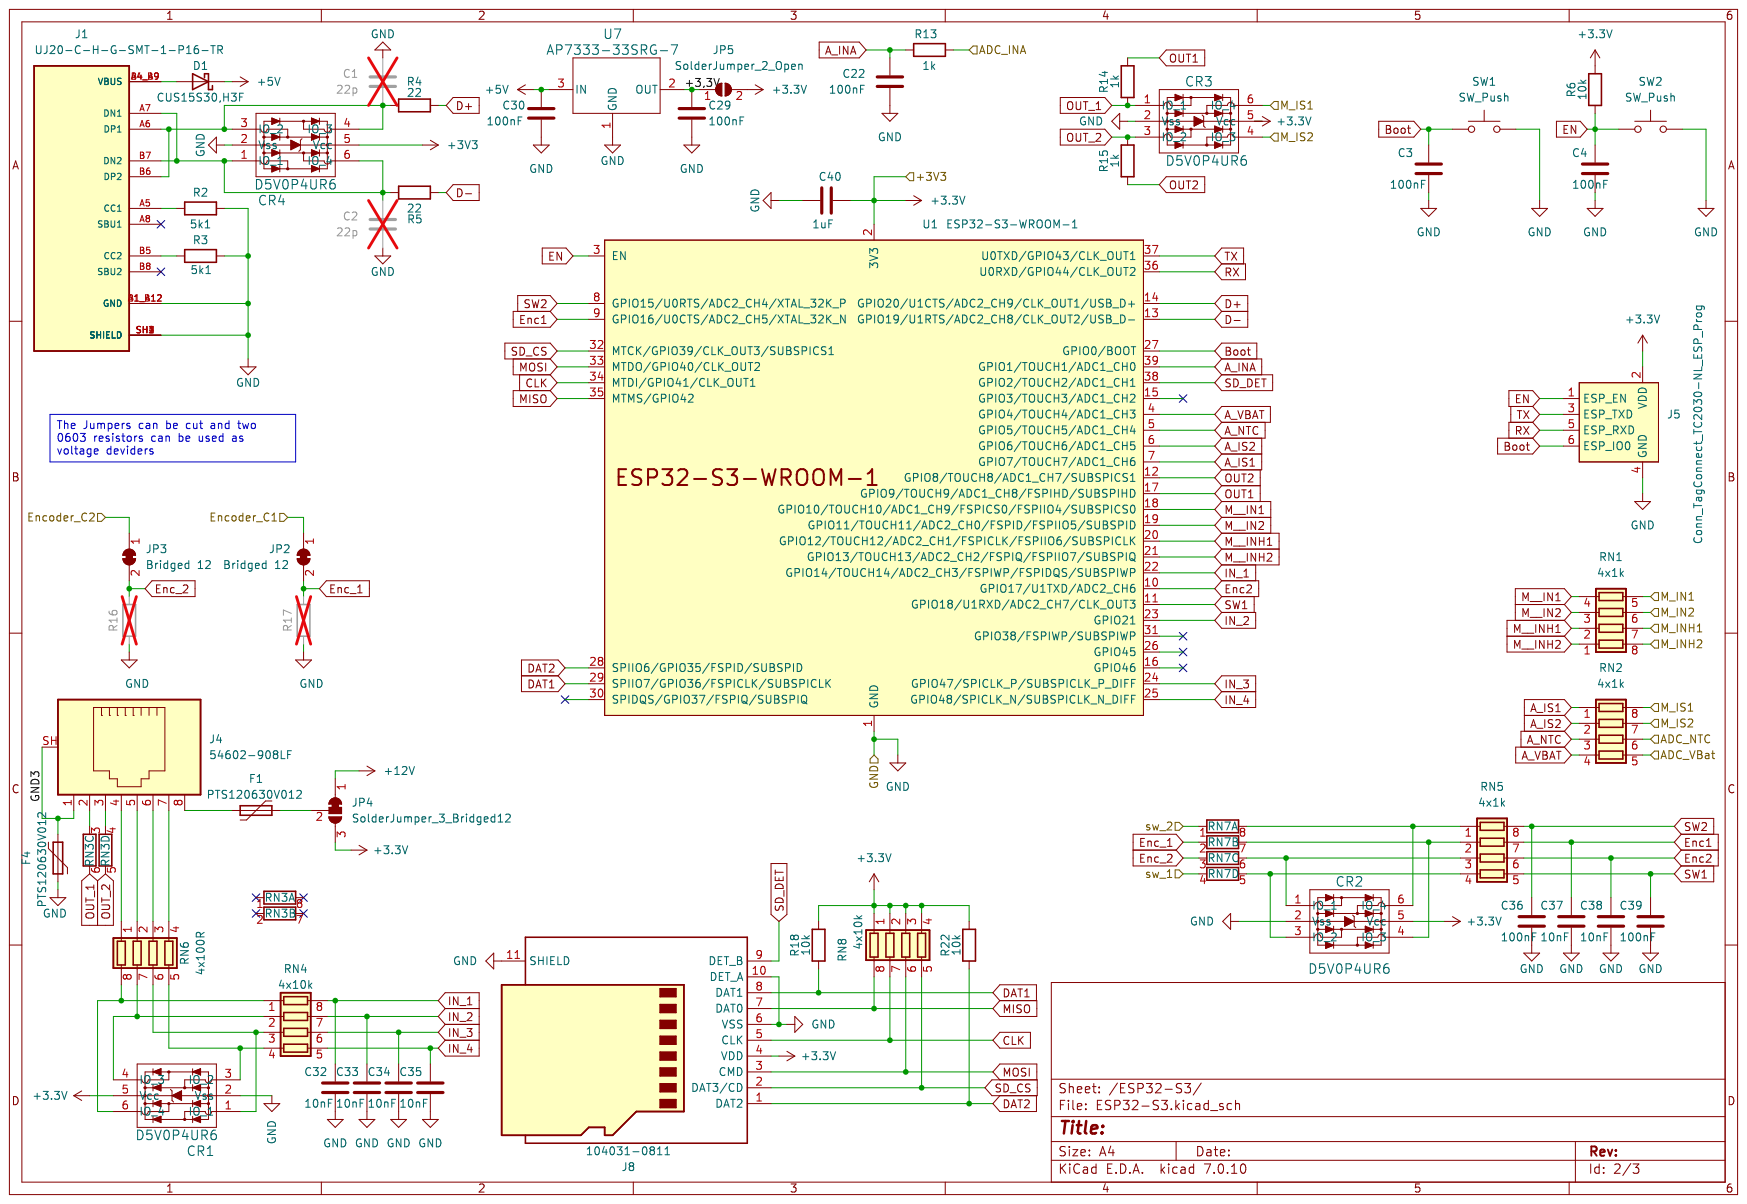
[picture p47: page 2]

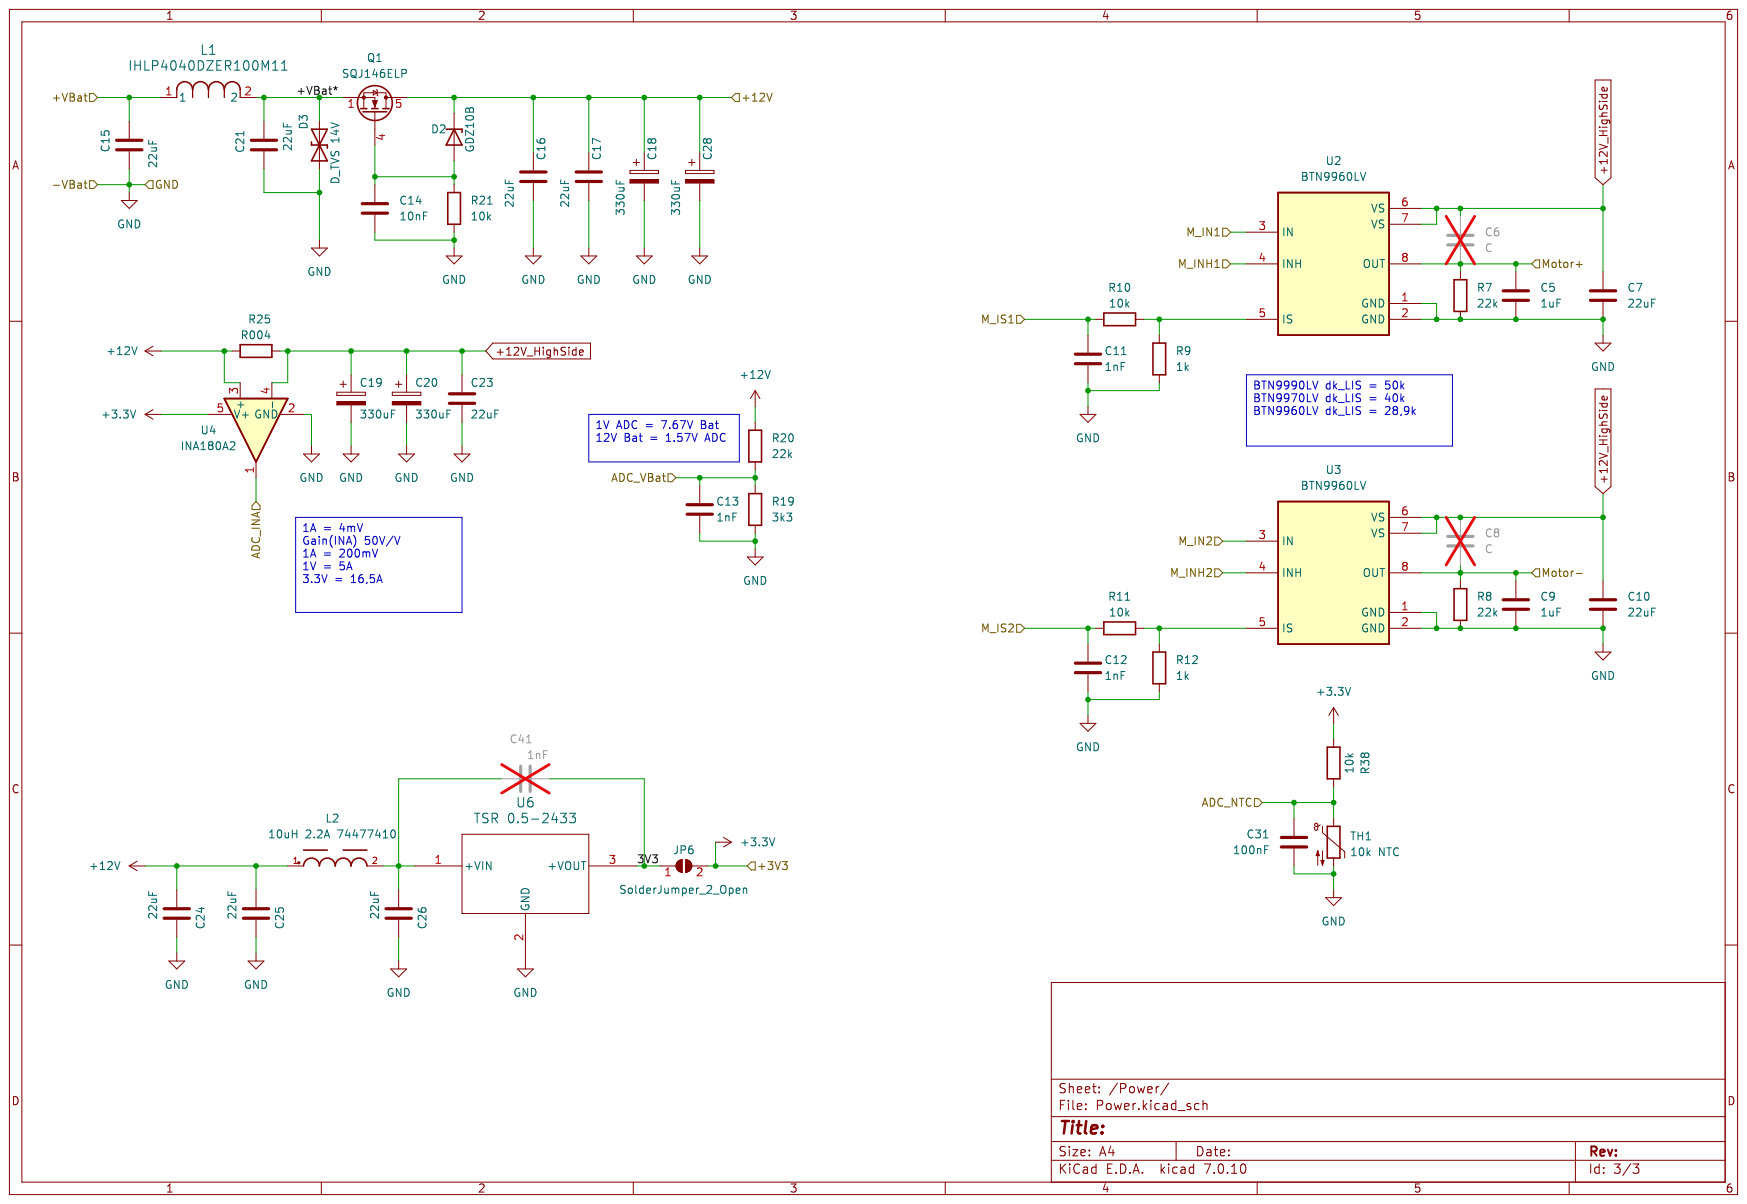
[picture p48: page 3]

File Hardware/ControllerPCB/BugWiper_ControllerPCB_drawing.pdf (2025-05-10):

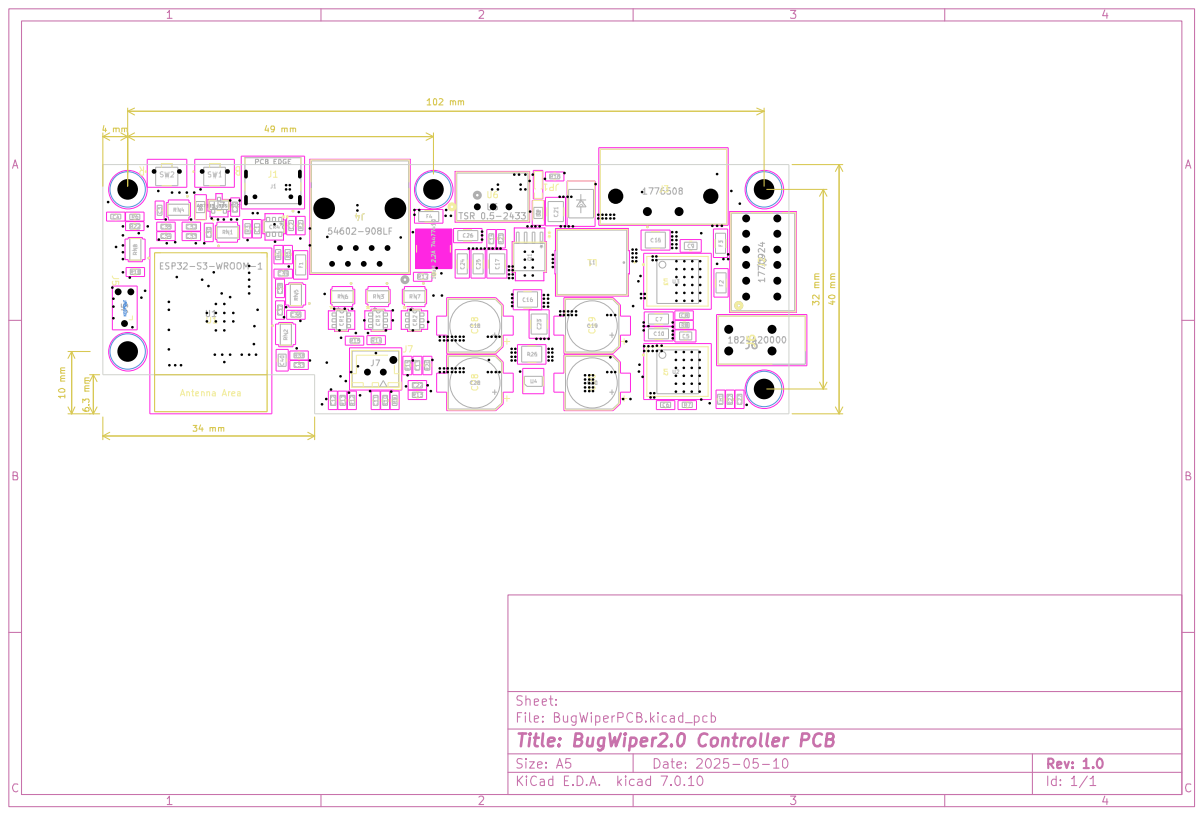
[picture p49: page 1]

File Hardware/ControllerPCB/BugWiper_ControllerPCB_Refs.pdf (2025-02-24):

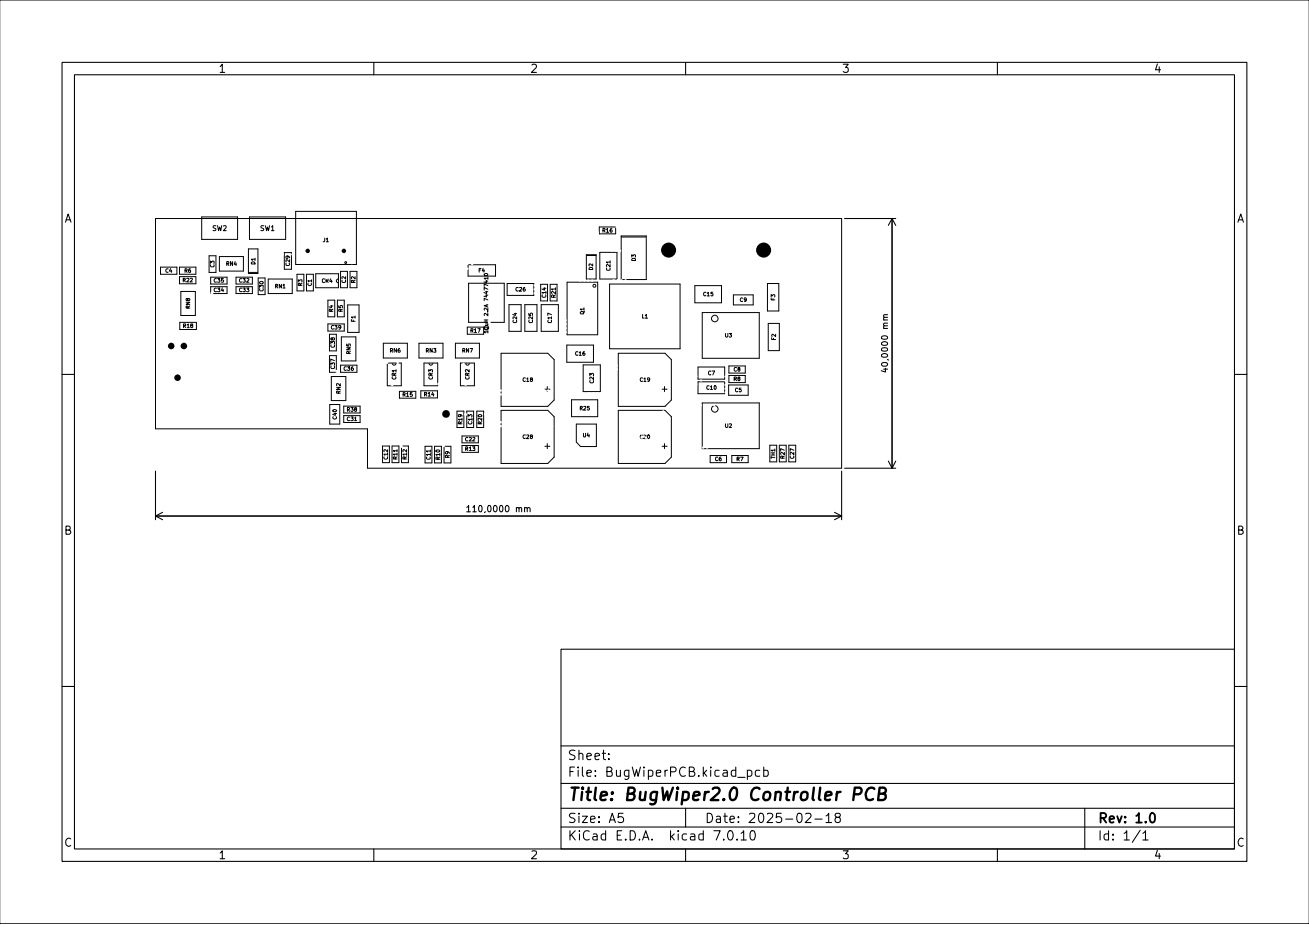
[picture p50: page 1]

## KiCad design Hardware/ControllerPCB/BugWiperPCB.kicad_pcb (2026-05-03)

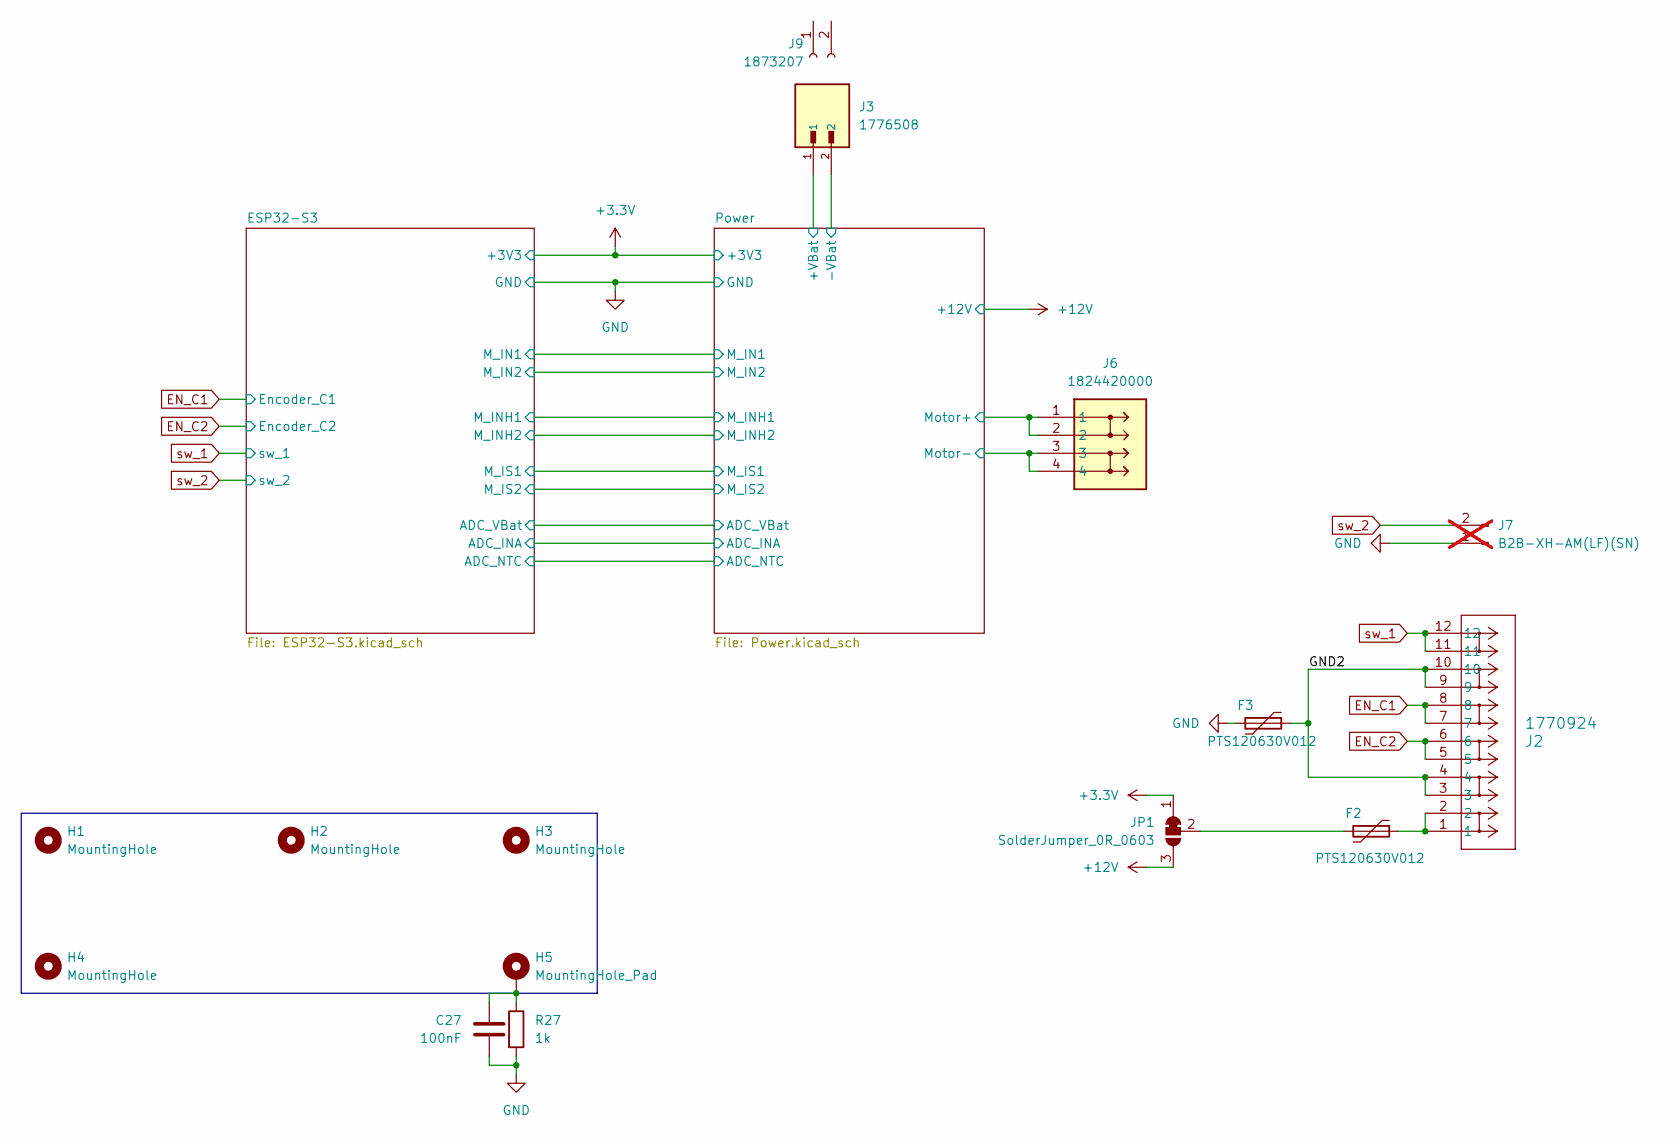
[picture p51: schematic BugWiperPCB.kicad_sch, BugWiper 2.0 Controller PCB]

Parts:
C27: 100nF; C_0603_1608Metric; Manufacturer_Part_Number CL10B104KB8NNNC; Mouser Part Number 187-CL10B104KB8NNNC
F2, F3: PTS120630V012; R_1206_3216Metric; Manufacturer_Part_Number PTS120630V012; Mouser Part Number 504-PTS120630V012
H1, H2, H3, H4: MountingHole; MountingHole_3.2mm_M3_DIN965_Pad
H5: MountingHole_Pad; MountingHole_3.2mm_M3_DIN965_Pad_TopBottom
J2: 1770924; CONN_1814537; Manufacturer_Part_Number 1770924; Mouser Part Number 651-1770924
J3: 1776508; PHOENIX_1776508; Manufacturer_Part_Number 1776508; Mouser Part Number 651-1776508
J6: 1824420000; SHDR4W80P700X350_2X2_770X1400X850P; Mouser Part Number 470-1824420000
J7: B2B-XH-AM(LF)(SN); JST_XH_B2B-XH-AM_1x02_P2.50mm_Vertical; Manufacturer_Part_Number B2B-XH-AM(LF)(SN); Mouser Part Number 306-B2B-XH-AMLFSNP; not fitted
J9: 1873207; Manufacturer_Part_Number 1873207; Mouser Part Number 651-1873207
JP1: SolderJumper_0R_0603; SolderJumper_R_SMD_0603; Manufacturer_Part_Number RC0603FR-070RL; Mouser Part Number 603-RC0603FR-070RL
R27: 1k; R_0603_1608Metric; Manufacturer_Part_Number RC0603FR-071KL; Mouser Part Number 603-RC0603FR-071KL

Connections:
+3.3V: JP1.1 (A); also elsewhere on the board
+12V: JP1.3 (B); also elsewhere on the board
/GND2: F3.1, J2.3, J2.4, J2.9, J2.10
/Power/+VBat: J3.1; also elsewhere on the board
/Power/Motor+: J6.1, J6.2; also elsewhere on the board
/Power/Motor-: J6.3, J6.4; also elsewhere on the board
EN_C1: J2.7, J2.8; also elsewhere on the board
EN_C2: J2.5, J2.6; also elsewhere on the board
GND: C27.2, F3.2, J3.2, J7.1, R27.2; also elsewhere on the board
unnamed: C27.1, H5.1, R27.1
unnamed: F2.1, J2.1, J2.2
unnamed: F2.2, JP1.2 (C)
sw_1: J2.11, J2.12; also elsewhere on the board
sw_2: J7.2; also elsewhere on the board

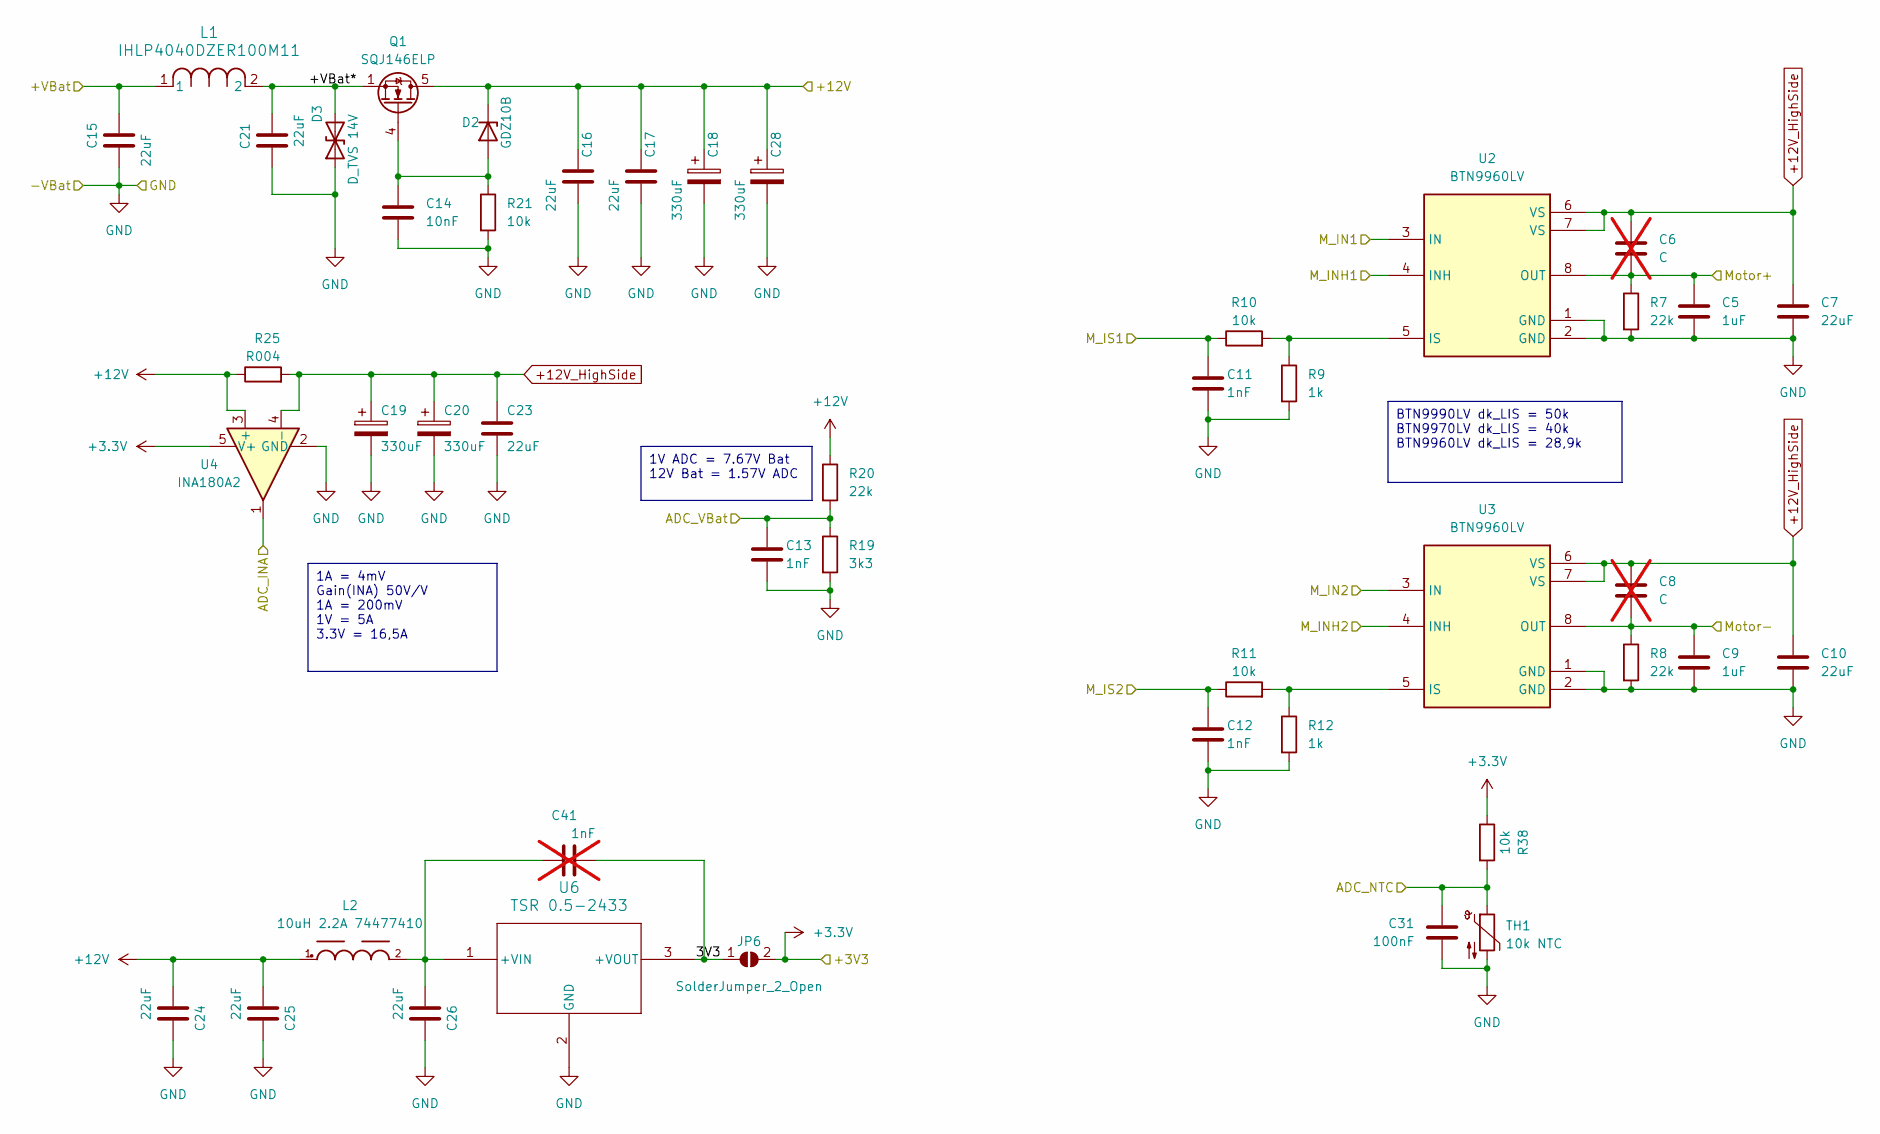
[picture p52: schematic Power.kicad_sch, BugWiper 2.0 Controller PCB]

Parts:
C5, C9: 1uF; C_0805_2012Metric; Manufacturer_Part_Number CL21B105MBFNNNE; Mouser Part Number 187-CL21B105MBFNNNE
C6, C8: C; C_0603_1608Metric; not fitted
C7, C10, C24, C25, C26: 22uF; C_1206_3216Metric; Manufacturer_Part_Number CL31A226KAHNNNE; Mouser Part Number 187-CL31A226KAHNNNE
C11, C12, C13: 1nF; C_0603_1608Metric; Manufacturer_Part_Number KAM15AR71H102KM; Mouser Part Number 581-KAM15AR71H102KM
C14: 10nF; C_0603_1608Metric; Manufacturer_Part_Number CL10B103KB8NFNC; Mouser Part Number 187-CL10B103KB8NFNC
C15, C16, C17, C21, C23: 22uF; C_1210_3225Metric; Manufacturer_Part_Number CL31A226KAHNNNE; Mouser Part Number 187-CL31A226KAHNNNE
C18, C19, C20, C28: 330uF; CP_Elec_8x10.5; Manufacturer_Part_Number UWT1E331MNL1GS; Mouser Part Number 647-UWT1E331MNL1S
C31: 100nF; C_0603_1608Metric; Manufacturer_Part_Number CL10B104KB8NNNC; Mouser Part Number 187-CL10B104KB8NNNC
C41: 1nF; C_0805_2012Metric_Pad1.18x1.45mm_HandSolder; not fitted
D2: GDZ10B; D_SOD-323_HandSoldering; Manufacturer_Part_Number GDZ10B-E3-08; Mouser Part Number 78-GDZ10B-E3-08
D3: D_TVS 14V; D_SMB; Manufacturer_Part_Number SMBJ14CA-13-F; Mouser Part Number 621-SMBJ14CA-13-F
JP6: SolderJumper_2_Open; SolderJumper-2_P1.3mm_Open_TrianglePad1.0x1.5mm
L1: IHLP4040DZER100M11; IND_IHLP-4040DZ_VIS; Manufacturer_Part_Number IHLP4040DZER100M11; Mouser Part Number 70-IHLP4040DZER100M1
L2: 10uH 2.2A 74477410; WE-PD2_5848; Manufacturer_Part_Number 74477410; Mouser Part Number 710-74477410
Q1: SQJ146ELP; PowerPAK_SO-8L_3_VIS; Manufacturer_Part_Number SQJ146ELP-T1_GE3; Mouser Part Number 78-SQJ146ELP-T1_GE3
R7, R8, R20: 22k; R_0603_1608Metric; Manufacturer_Part_Number AC0603FR-1022KL; Mouser Part Number 603-AC0603FR-1022KL
R9, R12: 1k; R_0603_1608Metric; Manufacturer_Part_Number RC0603FR-071KL; Mouser Part Number 603-RC0603FR-071KL
R10, R11, R21, R38: 10k; R_0603_1608Metric; Manufacturer_Part_Number RC0603FR-1010KL; Mouser Part Number 603-RC0603FR-1010KL
R19: 3k3; R_0603_1608Metric; Manufacturer_Part_Number CR0603-FX-3301ELF; Mouser Part Number 652-CR0603-FX3301ELF
R25: R004; R_1210_3225Metric; Manufacturer_Part_Number LRMAM1206-R004FT5; Mouser Part Number 756-LRMAM1206R004FT5
TH1: 10k NTC; R_0603_1608Metric; Manufacturer_Part_Number NCU18XH103E60RB; Mouser Part Number 81-NCU18XH103E60RB
U2, U3: BTN9960LV; IFX-PG-HSOF-7-1-V; Manufacturer_Part_Number BTN9960LVAUMA1; Mouser Part Number 726-BTN9960LVAUMA1
U4: INA180A2; SOT-23-5; Manufacturer_Part_Number INA180A2IDBVT; Mouser Part Number 595-INA180A2IDBVT
U6: TSR 0.5-2433; TSR0P5_TRP; Manufacturer_Part_Number R-78E3.3-0.5; Mouser Part Number 919-R-78E3.3-0.5

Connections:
+3.3V: JP6.2 (B), R38.1, U4.5 (V+); also elsewhere on the board
+12V: C16.1, C17.1, C18.1, C24.2, C25.2, C28.1, D2.1 (K), L2.1, Q1.5 (D), R20.1, R25.1, U4.3 (+); also elsewhere on the board
+12V_HighSide: C6.1, C7.1, C8.1, C10.1, C19.1, C20.1, C23.1, R25.2, U2.6 (VS), U2.7 (VS), U3.6 (VS), U3.7 (VS), U4.4 (-)
/ESP32-S3/ADC_INA: U4.1; also elsewhere on the board
/ESP32-S3/ADC_NTC: C31.1, R38.2, TH1.1; also elsewhere on the board
/ESP32-S3/ADC_VBat: C13.1, R19.1, R20.2; also elsewhere on the board
/ESP32-S3/M_IN1: U2.3 (IN); also elsewhere on the board
/ESP32-S3/M_IN2: U3.3 (IN); also elsewhere on the board
/ESP32-S3/M_INH1: U2.4 (INH); also elsewhere on the board
/ESP32-S3/M_INH2: U3.4 (INH); also elsewhere on the board
/ESP32-S3/M_IS1: C11.1, R10.1; also elsewhere on the board
/ESP32-S3/M_IS2: C12.1, R11.1; also elsewhere on the board
/Power/3V3: C41.2, JP6.1 (A), U6.3 (+VOUT)
/Power/+VBat: C15.1, L1.1; also elsewhere on the board
/Power/+VBat*: C21.2, D3.2 (A2), L1.2, Q1.1 (S), Q1.2 (S), Q1.3 (S)
/Power/Motor+: C5.1, C6.2, R7.1, U2.8 (OUT); also elsewhere on the board
/Power/Motor-: C8.2, C9.1, R8.1, U3.8 (OUT); also elsewhere on the board
GND: C5.2, C7.2, C9.2, C10.2, C11.2, C12.2, C13.2, C14.2, C15.2, C16.2, C17.2, C18.2, C19.2, C20.2, C21.1, C23.2, C24.1, C25.1, C26.1, C28.2, C31.2, D3.1 (A1), R7.2, R8.2, R9.2, R12.2, R19.2, R21.2, TH1.2, U2.1 (GND), U2.2 (GND), U3.1 (GND), U3.2 (GND), U4.2 (GND), U6.2 (GND); also elsewhere on the board
unnamed: C14.1, D2.2 (A), Q1.4 (G), R21.1
unnamed: R9.1, R10.2, U2.5 (IS)
unnamed: R11.2, R12.1, U3.5 (IS)
unnamed: C26.2, C41.1, L2.2, U6.1 (+VIN)

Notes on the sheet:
1A = 4mV Gain(INA) 50V/V 1A = 200mV 1V = 5A 3.3V = 16,5A
1V ADC = 7.67V Bat 12V Bat = 1.57V ADC
BTN9990LV dk_LIS = 50k BTN9970LV dk_LIS = 40k BTN9960LV dk_LIS = 28,9k

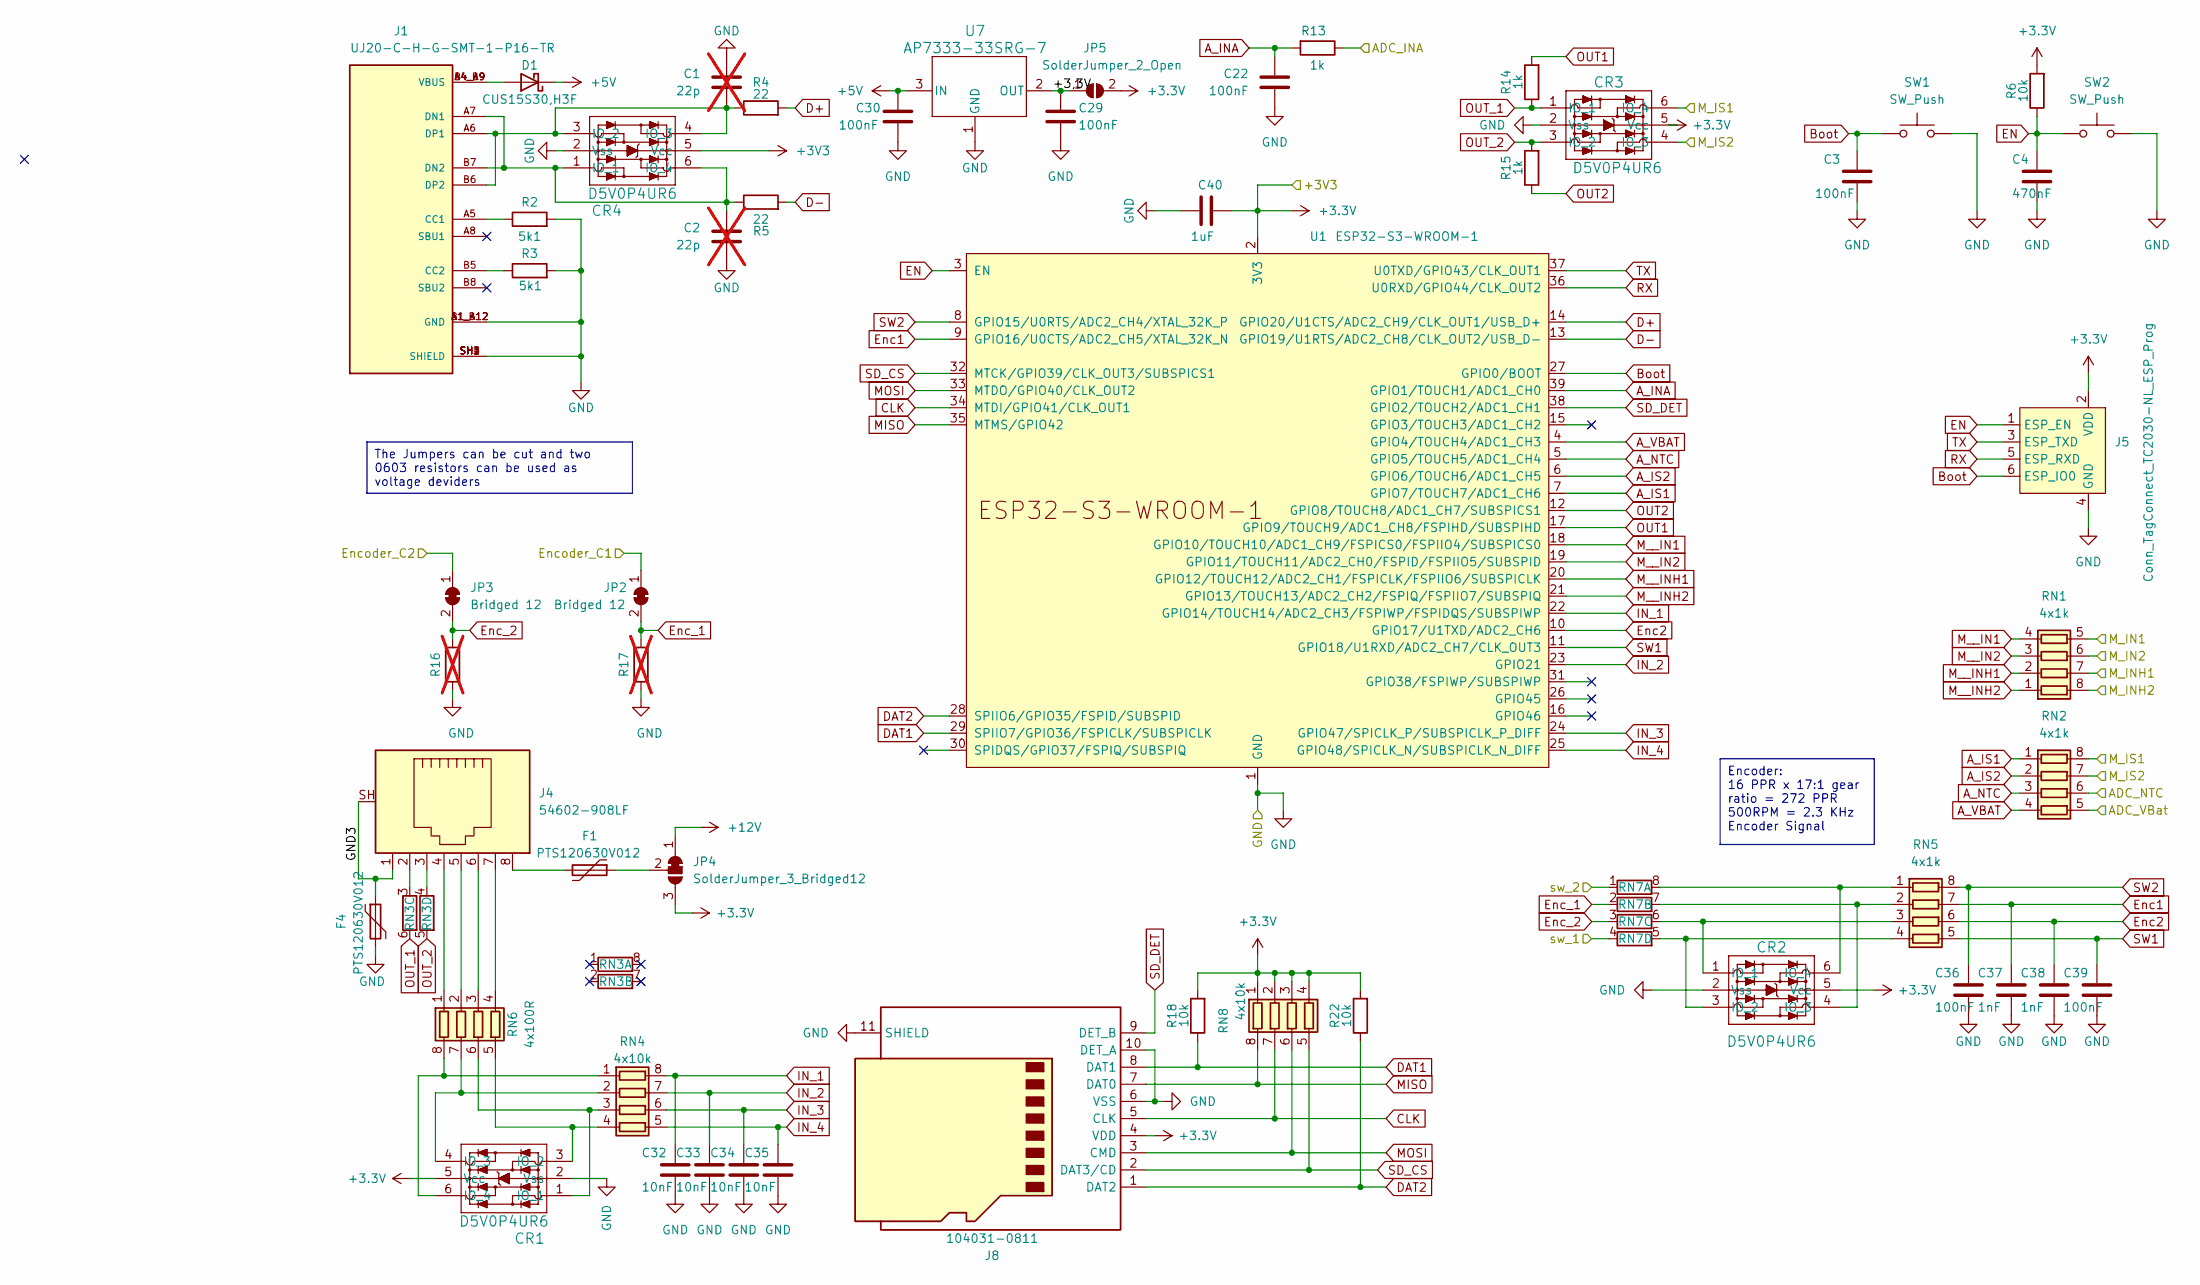
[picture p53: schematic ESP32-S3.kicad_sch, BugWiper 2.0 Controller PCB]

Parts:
C1, C2: 22p; C_0603_1608Metric; not fitted
C3, C22, C29, C30, C39: 100nF; C_0603_1608Metric; Manufacturer_Part_Number CL10B104KB8NNNC; Mouser Part Number 187-CL10B104KB8NNNC
C4: 470nF; C_0603_1608Metric; Manufacturer_Part_Number CL10B474KA8NFNC; Mouser Part Number 187-CL10B474KA8NFNC
C32, C33, C34, C35: 10nF; C_0603_1608Metric; Manufacturer_Part_Number CL10B103KB8NFNC; Mouser Part Number 187-CL10B103KB8NFNC
C36: 100nF; C_0603_1608Metric; Manufacturer_Part_Number CL10B103KB8NFNC; Mouser Part Number 187-CL10B103KB8NFNC
C37: 1nF; C_0603_1608Metric; Manufacturer_Part_Number CL10B103KB8NFNC; Mouser Part Number 187-CL10B103KB8NFNC
C38: 1nF; C_0603_1608Metric; Manufacturer_Part_Number CL10B104KB8NNNC; Mouser Part Number 187-CL10B104KB8NNNC
C40: 1uF; C_0805_2012Metric; Manufacturer_Part_Number CL21B105MBFNNNE; Mouser Part Number 187-CL21B105MBFNNNE
CR1, CR2, CR3, CR4: D5V0P4UR6; SOT26_DIO; Manufacturer_Part_Number D5V0P4UR6SO-7; Mouser Part Number 621-D5V0P4UR6SO-7
D1: CUS15S30,H3F; D_SOD-323_HandSoldering; Manufacturer_Part_Number CUS15S30,H3F; Mouser Part Number 757-CUS15S30H3F
F1, F4: PTS120630V012; R_1206_3216Metric; Manufacturer_Part_Number PTS120630V012; Mouser Part Number 504-PTS120630V012
J1: UJ20-C-H-G-SMT-1-P16-TR; SAMESKY_UJ20-C-H-G-SMT-1-P16-TR; Manufacturer_Part_Number UJ20-C-H-G-SMT-1-P16-TR; Mouser Part Number 179-UJ20CHGSMT1P16TR
J4: 54602-908LF; CONN8_2-908LF_AMP; Manufacturer_Part_Number 54602-908LF; Mouser Part Number 649-54602-908LF
J5: Conn_TagConnect_TC2030-NL_ESP_Prog; Tag-Connect_TC2030-IDC-NL_2x03_P1.27mm_Vertical; Mouser Price/Stock 0€
J8: 104031-0811; microSD_HC_Molex_104031-0811; Manufacturer_Part_Number 104031-0811; Mouser Part Number 538-104031-0811
JP2, JP3: Bridged 12; SolderJumper_2P_R_SMD_0603_Bridged
JP4: SolderJumper_3_Bridged12; SolderJumper_3P_R_SMD_0603_Bridged_12
JP5: SolderJumper_2_Open; SolderJumper-2_P1.3mm_Open_TrianglePad1.0x1.5mm
R2, R3: 5k1; R_0603_1608Metric; Manufacturer_Part_Number RC0603FR-105K1L; Mouser Part Number 603-RC0603FR-105K1L
R4, R5: 22; R_0603_1608Metric; Manufacturer_Part_Number CR0603-FX-22R0ELF; Mouser Part Number 652-CR0603FX-22R0ELF
R6, R18, R22: 10k; R_0603_1608Metric; Manufacturer_Part_Number RC0603FR-1010KL; Mouser Part Number 603-RC0603FR-1010KL
R13, R14, R15: 1k; R_0603_1608Metric; Manufacturer_Part_Number RC0603FR-071KL; Mouser Part Number 603-RC0603FR-071KL
R16, R17: R_0603_1608Metric; not fitted
RN1, RN2, RN5: 4x1k; RESCAV80P320X155X60-8N; Manufacturer_Part_Number CAY16-1001F4LF; Mouser Part Number 652-CAY16-1001F4LF
RN3, RN6, RN7: 4x100R; RESCAV80P320X155X60-8N; Manufacturer_Part_Number CAT16A-1000F4LF; Mouser Part Number 652-CAT16A-1000F4LF
RN4, RN8: 4x10k; RESCAV80P320X155X60-8N; Manufacturer_Part_Number CAT16A-1002F4LF; Mouser Part Number 652-CAT16A-1002F4LF
SW1, SW2: SW_Push; EVQ9P701P; Manufacturer_Part_Number EVQ-P3401P; Mouser Part Number 667-EVQP3401P
U1: ESP32-S3-WROOM-1; Manufacturer_Part_Number ESP32-S3-WROOM-1-N16R8; Mouser Part Number 356-ESP32S3WRM1N16R8
U7: AP7333-33SRG-7; SOT23R_DIO; Manufacturer_Part_Number AP7333-33SRG-7; Mouser Part Number 621-AP7333-33SRG-7

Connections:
+3.3V: C40.2, CR1.5 (Vcc), CR2.5 (Vcc), CR3.5 (Vcc), CR4.5 (Vcc), J5.2 (VDD), J8.4 (VDD), JP4.3 (B), JP5.2 (B), R6.2, R18.2, R22.2, RN8.1 (R1.1), RN8.2 (R2.1), RN8.3 (R3.1), RN8.4 (R4.1), U1.2 (3V3); also elsewhere on the board
+5V: C30.1, D1.1 (K), U7.3 (IN)
+12V: JP4.1 (A); also elsewhere on the board
/ESP32-S3/+3,3V: C29.1, JP5.1 (A), U7.2 (OUT)
/ESP32-S3/ADC_INA: R13.1; also elsewhere on the board
/ESP32-S3/ADC_NTC: RN2.6 (R3.2); also elsewhere on the board
/ESP32-S3/ADC_VBat: RN2.5 (R4.2); also elsewhere on the board
/ESP32-S3/GND3: F4.1, J4.1, J4.SH
/ESP32-S3/M_IN1: RN1.5 (R4.2); also elsewhere on the board
/ESP32-S3/M_IN2: RN1.6 (R3.2); also elsewhere on the board
/ESP32-S3/M_INH1: RN1.7 (R2.2); also elsewhere on the board
/ESP32-S3/M_INH2: RN1.8 (R1.2); also elsewhere on the board
/ESP32-S3/M_IS1: CR3.6 (IO_4), RN2.8 (R1.2); also elsewhere on the board
/ESP32-S3/M_IS2: CR3.4 (IO_3), RN2.7 (R2.2); also elsewhere on the board
A_INA: C22.1, R13.2, U1.39 (GPIO1/TOUCH1/ADC1_CH0)
A_IS1: RN2.1 (R1.1), U1.7 (GPIO7/TOUCH7/ADC1_CH6)
A_IS2: RN2.2 (R2.1), U1.6 (GPIO6/TOUCH6/ADC1_CH5)
A_NTC: RN2.3 (R3.1), U1.5 (GPIO5/TOUCH5/ADC1_CH4)
A_VBAT: RN2.4 (R4.1), U1.4 (GPIO4/TOUCH4/ADC1_CH3)
Boot: C3.1, J5.6 (ESP_IO0), SW1.1, U1.27 (GPIO0/BOOT)
CLK: J8.5 (CLK), RN8.7 (R2.2), U1.34 (MTDI/GPIO41/CLK_OUT1)
D+: R4.2, U1.14 (GPIO20/U1CTS/ADC2_CH9/CLK_OUT1/USB_D+)
D-: R5.2, U1.13 (GPIO19/U1RTS/ADC2_CH8/CLK_OUT2/USB_D-)
DAT1: J8.8 (DAT1), R18.1, U1.29 (SPIIO7/GPIO36/FSPICLK/SUBSPICLK)
DAT2: J8.1 (DAT2), R22.1, U1.28 (SPIIO6/GPIO35/FSPID/SUBSPID)
EN: C4.1, J5.1 (ESP_EN), R6.1, SW2.1, U1.3 (EN)
EN_C1: JP2.1 (A); also elsewhere on the board
EN_C2: JP3.1 (A); also elsewhere on the board
Enc1: C37.1, RN5.7 (R2.2), U1.9 (GPIO16/U0CTS/ADC2_CH5/XTAL_32K_N)
Enc2: C38.1, RN5.6 (R3.2), U1.10 (GPIO17/U1TXD/ADC2_CH6)
Enc_1: JP2.2 (A), R17.2, RN7.2 (R2.1)
Enc_2: JP3.2 (A), R16.2, RN7.3 (R3.1)
GND: C1.1, C2.2, C3.2, C4.2, C22.2, C29.2, C30.2, C32.2, C33.2, C34.2, C35.2, C36.2, C37.2, C38.2, C39.2, C40.1, CR1.2 (Vss), CR2.2 (Vss), CR3.2 (Vss), CR4.2 (Vss), F4.2, J1.A1_B12 (GND), J1.B1_A12 (GND), J1.SH1 (SHIELD), J1.SH2 (SHIELD), J1.SH3 (SHIELD), J1.SH4 (SHIELD), J5.4 (GND), J8.6 (VSS), J8.10 (DET_A), J8.11 (SHIELD), R2.2, R3.2, R16.1, R17.1, SW1.2, SW2.2, U1.1 (GND), U1.40 (GND), U1.41 (GND), U7.1 (GND); also elsewhere on the board
IN_1: C32.1, RN4.8 (R1.2), U1.22 (GPIO14/TOUCH14/ADC2_CH3/FSPIWP/FSPIDQS/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)
IN_2: C33.1, RN4.7 (R2.2), U1.23 (GPIO21)
IN_3: C34.1, RN4.6 (R3.2), U1.24 (GPIO47/SPICLK_P/SUBSPICLK_P_DIFF)
IN_4: C35.1, RN4.5 (R4.2), U1.25 (GPIO48/SPICLK_N/SUBSPICLK_N_DIFF)
MISO: J8.7 (DAT0), RN8.8 (R1.2), U1.35 (MTMS/GPIO42)
MOSI: J8.3 (CMD), RN8.6 (R3.2), U1.33 (MTDO/GPIO40/CLK_OUT2)
M__IN1: RN1.4 (R4.1), U1.18 (GPIO10/TOUCH10/ADC1_CH9/FSPICS0/FSPIIO4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)
M__IN2: RN1.3 (R3.1), U1.19 (GPIO11/TOUCH11/ADC2_CH0/FSPID/FSPIIO5/S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)
M__INH1: RN1.2 (R2.1), U1.20 (GPIO12/TOUCH12/ADC2_CH1/FSPICLK/FSPIIO6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)
M__INH2: RN1.1 (R1.1), U1.21 (GPIO13/TOUCH13/ADC2_CH2/FSPIQ/FSPIIO7/S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)
unnamed: CR1.1 (IO_1), RN4.3 (R3.1), RN6.6 (R3.2)
unnamed: CR1.3 (IO_2), RN4.4 (R4.1), RN6.5 (R4.2)
unnamed: CR1.4 (IO_3), RN4.2 (R2.1), RN6.7 (R2.2)
unnamed: CR1.6 (IO_4), RN4.1 (R1.1), RN6.8 (R1.2)
unnamed: CR2.1 (IO_1), RN5.3 (R3.1), RN7.6 (R3.2)
unnamed: CR2.3 (IO_2), RN5.4 (R4.1), RN7.5 (R4.2)
unnamed: CR2.4 (IO_3), RN5.2 (R2.1), RN7.7 (R2.2)
unnamed: CR2.6 (IO_4), RN5.1 (R1.1), RN7.8 (R1.2)
unnamed: C2.1, CR4.1 (IO_1), CR4.6 (IO_4), J1.A7 (DN1), J1.B7 (DN2), R5.1
unnamed: C1.2, CR4.3 (IO_2), CR4.4 (IO_3), J1.A6 (DP1), J1.B6 (DP2), R4.1
unnamed: D1.2 (A), J1.A4_B9 (VBUS), J1.B4_A9 (VBUS)
unnamed: F1.2, J4.8
unnamed: J1.A5 (CC1), R2.1
unnamed: J1.B5 (CC2), R3.1
unnamed: F1.1, JP4.2 (C)
unnamed: J4.2, RN3.3 (R3.1)
unnamed: J4.3, RN3.4 (R4.1)
unnamed: J4.4, RN6.1 (R1.1)
unnamed: J4.5, RN6.2 (R2.1)
unnamed: J4.6, RN6.3 (R3.1)
unnamed: J4.7, RN6.4 (R4.1)
OUT1: R14.2, U1.17 (GPIO9/TOUCH9/ADC1_CH8/FSPIHD/SUBSPIHD)
OUT2: R15.1, U1.12 (GPIO8/TOUCH8/ADC1_CH7/SUBSPICS1)
OUT_1: CR3.1 (IO_1), R14.1, RN3.6 (R3.2)
OUT_2: CR3.3 (IO_2), R15.2, RN3.5 (R4.2)
RX: J5.5 (ESP_RXD), U1.36 (U0RXD/GPIO44/CLK_OUT2)
SD_CS: J8.2 (DAT3/CD), RN8.5 (R4.2), U1.32 (MTCK/GPIO39/CLK_OUT3/SUBSPICS1)
SD_DET: J8.9 (DET_B), U1.38 (GPIO2/TOUCH2/ADC1_CH1)
SW1: C39.1, RN5.5 (R4.2), U1.11 (GPIO18/U1RXD/ADC2_CH7/CLK_OUT3)
SW2: C36.1, RN5.8 (R1.2), U1.8 (GPIO15/U0RTS/ADC2_CH4/XTAL_32K_P)
TX: J5.3 (ESP_TXD), U1.37 (U0TXD/GPIO43/CLK_OUT1)
sw_1: RN7.4 (R4.1); also elsewhere on the board
sw_2: RN7.1 (R1.1); also elsewhere on the board

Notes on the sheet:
Encoder: 16 PPR x 17:1 gear ratio = 272 PPR 500RPM = 2.3 KHz Encoder Signal
The Jumpers can be cut and two 0603 resistors can be used as voltage deviders

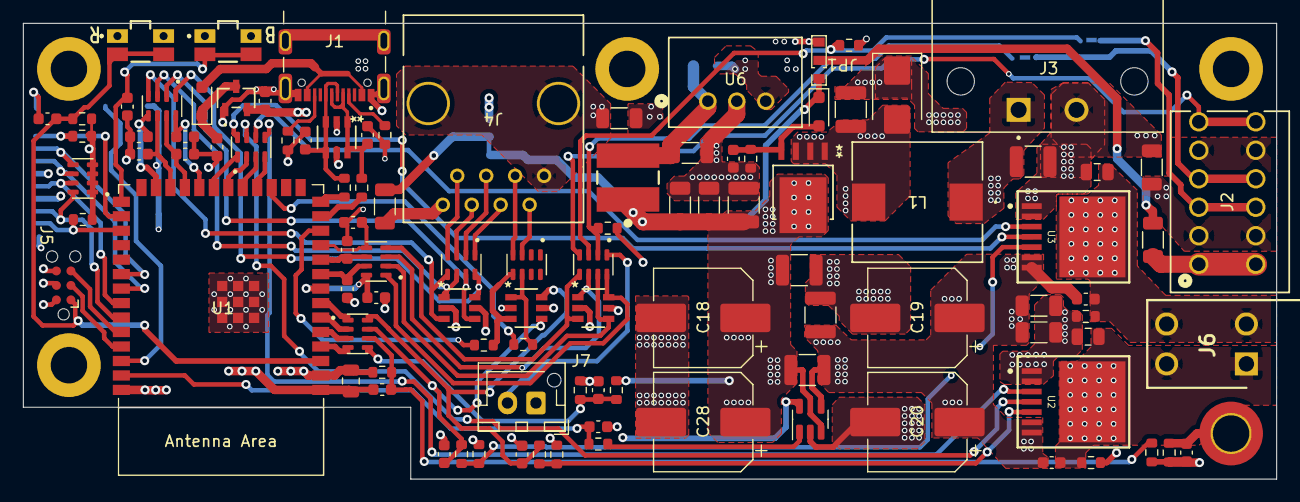
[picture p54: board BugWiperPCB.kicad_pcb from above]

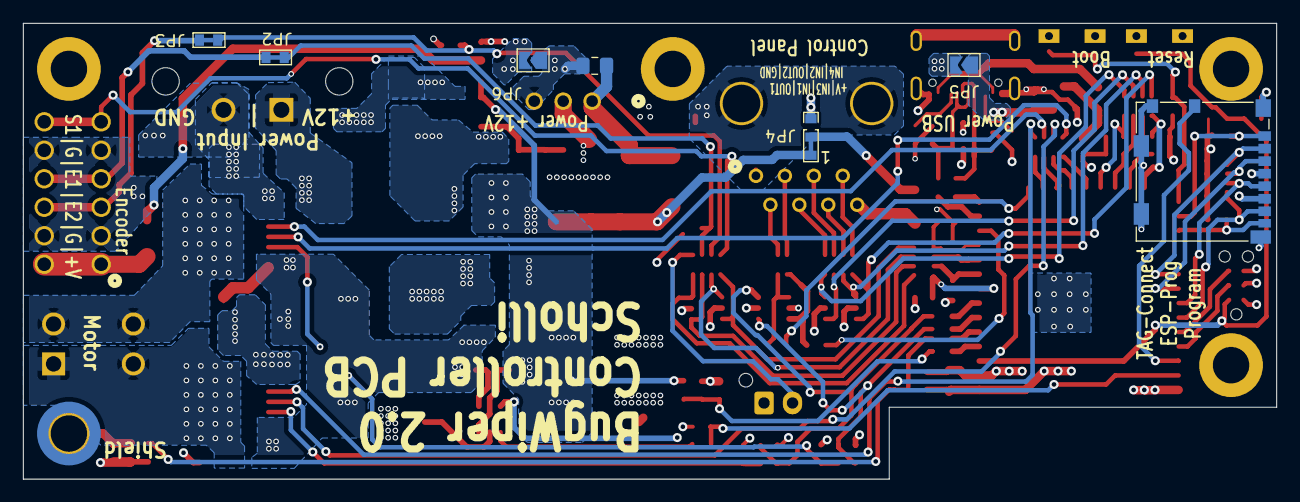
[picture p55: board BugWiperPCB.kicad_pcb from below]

Board: 4 copper layers, 110.0 x 40.0 mm, 115 parts (7 on the bottom side), 90 nets.

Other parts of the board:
locked: MountingHole; MountingHole_3.2mm_M3_DIN965_Pad

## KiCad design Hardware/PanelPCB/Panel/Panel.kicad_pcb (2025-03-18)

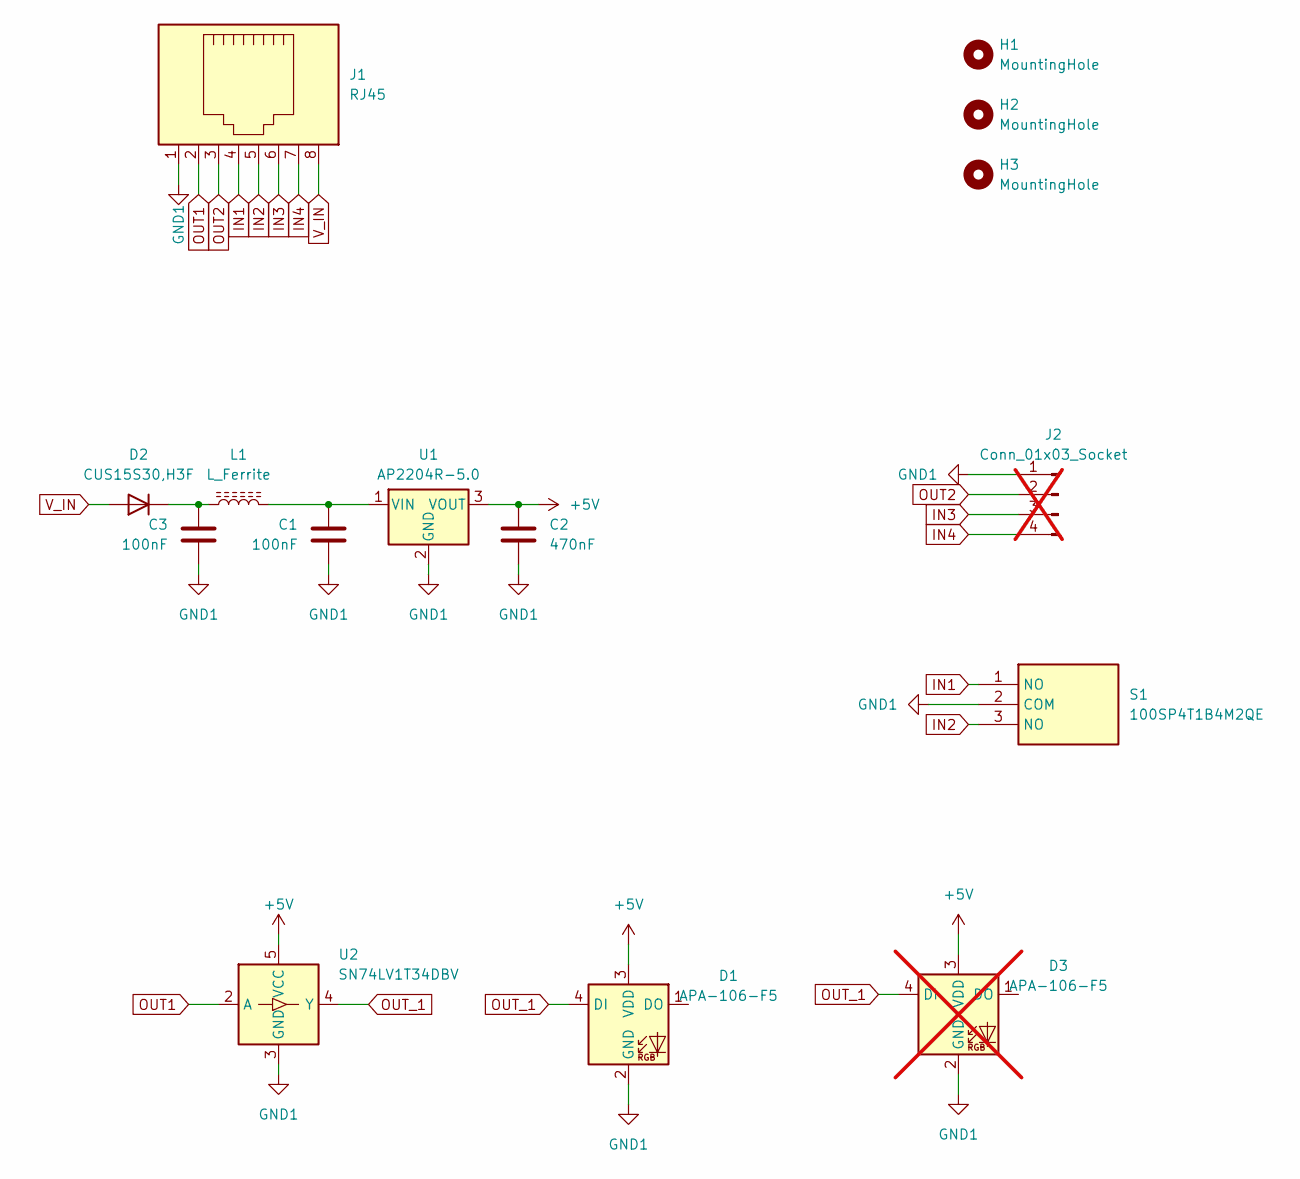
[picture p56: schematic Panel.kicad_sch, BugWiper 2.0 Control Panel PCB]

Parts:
C1, C3: 100nF; C_0603_1608Metric; Manufacturer_Part_Number CL10B104KB8NNNC; Mouser Part Number 187-CL10B104KB8NNNC
C2: 470nF; C_0603_1608Metric; Manufacturer_Part_Number CL10B474KA8NFNC; Mouser Part Number 187-CL10B474KA8NFNC
D1: APA-106-F5; LED_D5.0mm-4_RGB_Wide_Pins; Manufacturer_Part_Number APA-106-F5
D2: CUS15S30,H3F; D_SOD-323_HandSoldering; Manufacturer_Part_Number CUS15S30,H3F; Mouser Part Number 757-CUS15S30H3F
D3: APA-106-F5; LED_D5.0mm-4_RGB_Wide_Pins; Manufacturer_Part_Number APA-106-F5; not fitted
H1, H2, H3: MountingHole; MountingHole_2.7mm_M2.5_DIN965_Pad
J1: RJ45; MJ3415882; Manufacturer_Part_Number MJ3415-88-2; Mouser Part Number 640-MJ3415-88-2
J2: Conn_01x03_Socket; PinHeader_1x04_P2.54mm_Vertical; not fitted
L1: L_Ferrite; L_0805_2012Metric; Manufacturer_Part_Number ILBB0805ER151V; Mouser Part Number 70-ILBB0805ER151V
S1: 100SP4T1B4M2QE; Mouser Part Number 612-100SP4T1B4M2QE
U1: AP2204R-5.0; SOT-89-3; Manufacturer_Part_Number AP2204R-5.0TRG1; Mouser Part Number 621-AP2204R-5.0TRG1
U2: SN74LV1T34DBV; SOT-23-5; Manufacturer_Part_Number SN74LV1T34DBVR; Mouser Part Number 595-SN74LV1T34DBVR

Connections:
+5V: C2.1, D1.3 (VDD), D3.3 (VDD), U1.3 (VOUT), U2.5 (VCC)
GND1: C1.2, C2.2, C3.2, D1.2 (GND), D3.2 (GND), J1.1, J2.1, S1.2 (COM), U1.2 (GND), U2.3 (GND)
IN1: J1.4, S1.1 (NO)
IN2: J1.5, S1.3 (NO)
IN3: J1.6, J2.3
IN4: J1.7, J2.4
unnamed: C3.1, D2.1 (K), L1.1
unnamed: C1.1, L1.2, U1.1 (VIN)
OUT1: J1.2, U2.2 (A)
OUT2: J1.3, J2.2
OUT_1: D1.4 (DI), D3.4 (DI), U2.4 (Y)
V_IN: D2.2 (A), J1.8

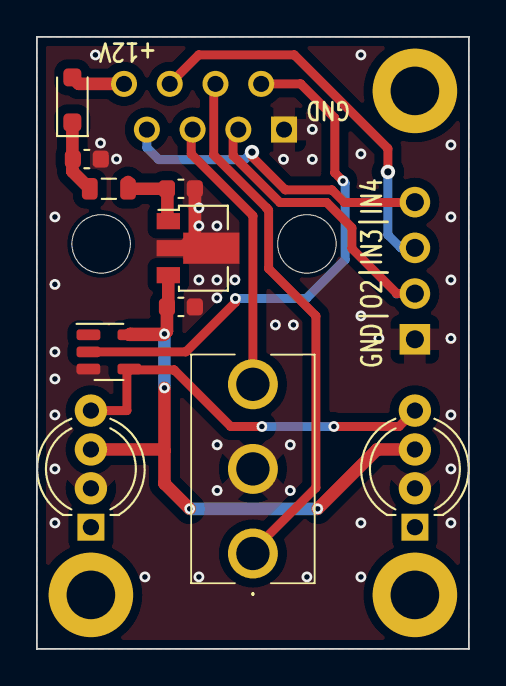
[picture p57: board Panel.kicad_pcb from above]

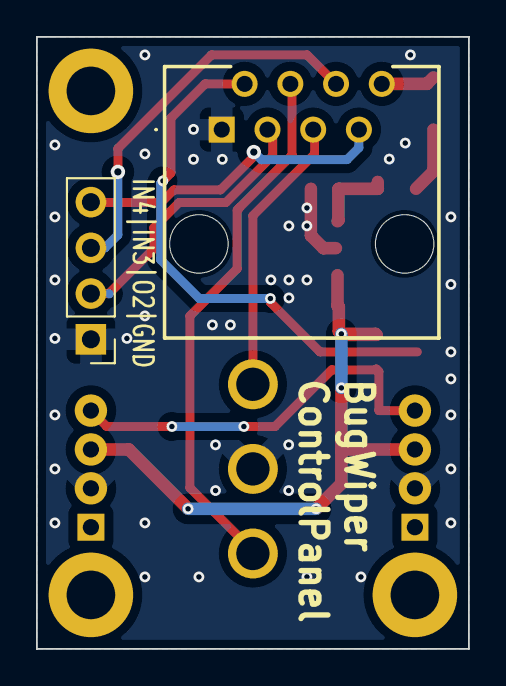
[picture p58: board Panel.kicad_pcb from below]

Board: 2 copper layers, 24.0 x 34.0 mm, 15 parts (2 on the bottom side), 12 nets.

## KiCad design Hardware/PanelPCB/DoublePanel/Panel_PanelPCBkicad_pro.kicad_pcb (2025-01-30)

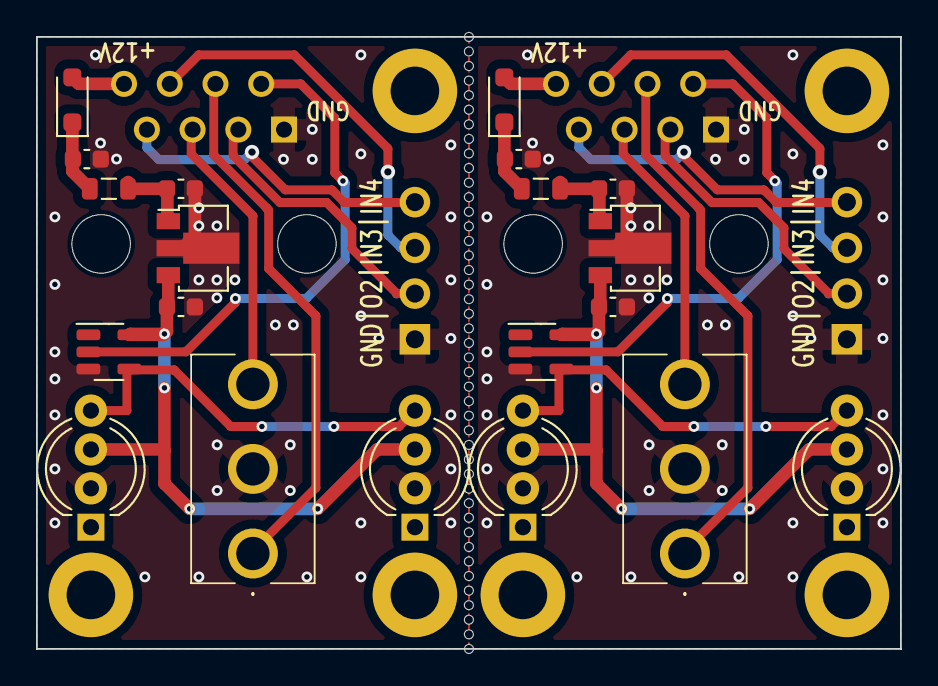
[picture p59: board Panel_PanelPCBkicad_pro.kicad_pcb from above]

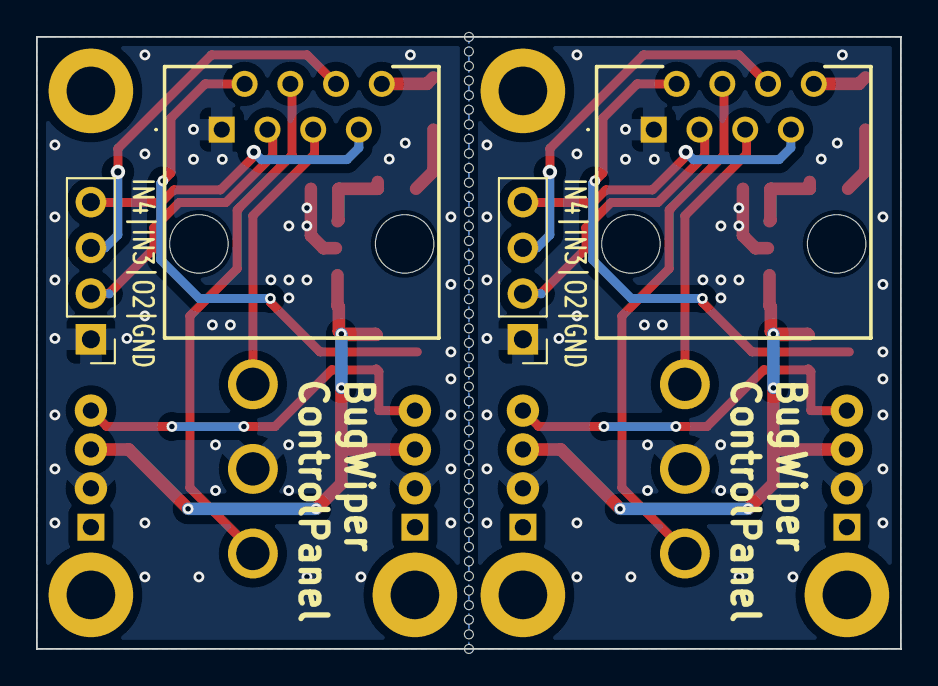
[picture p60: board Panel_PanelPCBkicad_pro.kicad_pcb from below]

Board: 2 copper layers, 48.0 x 34.0 mm, 73 parts (4 on the bottom side), 24 nets.

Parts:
C1, C1#2, C3, C3#2: 100nF; C_0603_1608Metric
C2, C2#2: 470nF; C_0603_1608Metric
D1, D1#2, D3, D3#2: APA-106-F5; LED_D5.0mm-4_RGB_Wide_Pins
D2, D2#2: CUS15S30,H3F; D_SOD-323_HandSoldering
H1, H1#2, H2, H2#2, H3, H3#2: MountingHole; MountingHole_2.7mm_M2.5_DIN965_Pad
J1, J1#2: RJ45; MJ3415882
J2, J2#2: Conn_01x03_Socket; PinHeader_1x04_P2.54mm_Vertical
KiKit_MB_1_1, KiKit_MB_1_2, KiKit_MB_1_3, KiKit_MB_1_4, KiKit_MB_1_5, KiKit_MB_1_6, KiKit_MB_1_7, KiKit_MB_1_8, KiKit_MB_1_9, KiKit_MB_1_10, KiKit_MB_1_11, KiKit_MB_1_12, KiKit_MB_1_13, KiKit_MB_1_14, KiKit_MB_1_15, KiKit_MB_1_16, KiKit_MB_1_17, KiKit_MB_1_18, KiKit_MB_1_19, KiKit_MB_1_20, KiKit_MB_1_21, KiKit_MB_1_22, KiKit_MB_1_23, KiKit_MB_1_24, KiKit_MB_1_25, KiKit_MB_1_26, KiKit_MB_1_27, KiKit_MB_1_28, KiKit_MB_1_29, KiKit_MB_1_30, KiKit_MB_1_31, KiKit_MB_1_32, KiKit_MB_1_33, KiKit_MB_1_34, KiKit_MB_1_35, KiKit_MB_1_36, KiKit_MB_1_37, KiKit_MB_1_38, KiKit_MB_1_39, KiKit_MB_1_40, KiKit_MB_1_41, KiKit_MB_1_42, KiKit_MB_1_43: NPTH
L1, L1#2: L_Ferrite; L_0805_2012Metric
S1, S1#2: 100SP4T1B4M2QE
U1, U1#2: AP2204R-5.0; SOT-89-3
U2, U2#2: SN74LV1T34DBV; SOT-23-5

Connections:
Board_0-+5V: C2#2.1, D1.3 (VDD), D3.3 (VDD), U1#2.3 (VOUT), U2#2.5 (VCC)
Board_0-GND1: C1.2, C2#2.2, C3.2, D1.2 (GND), D3.2 (GND), J1.1, J2#2.1, S1#2.2 (COM), U1#2.2 (GND), U2#2.3 (GND)
Board_0-IN1: J1.4, S1#2.1 (NO)
Board_0-IN2: J1.5, S1#2.3 (NO)
Board_0-IN3: J1.6, J2#2.3
Board_0-IN4: J1.7, J2#2.4
Board_0-Net-(D2-K): C3.1, D2#2.1 (K), L1.1
Board_0-Net-(U1-VIN): C1.1, L1.2, U1#2.1 (VIN)
Board_0-OUT1: J1.2, U2#2.2 (A)
Board_0-OUT2: J1.3, J2#2.2
Board_0-OUT_1: D1.4 (DI), D3.4 (DI), U2#2.4 (Y)
Board_0-V_IN: D2#2.2 (A), J1.8
Board_1-+5V: C2.1, D1#2.3 (VDD), D3#2.3 (VDD), U1.3 (VOUT), U2.5 (VCC)
Board_1-GND1: C1#2.2, C2.2, C3#2.2, D1#2.2 (GND), D3#2.2 (GND), J1#2.1, J2.1, S1.2 (COM), U1.2 (GND), U2.3 (GND)
Board_1-IN1: J1#2.4, S1.1 (NO)
Board_1-IN2: J1#2.5, S1.3 (NO)
Board_1-IN3: J1#2.6, J2.3
Board_1-IN4: J1#2.7, J2.4
Board_1-Net-(D2-K): C3#2.1, D2.1 (K), L1#2.1
Board_1-Net-(U1-VIN): C1#2.1, L1#2.2, U1.1 (VIN)
Board_1-OUT1: J1#2.2, U2.2 (A)
Board_1-OUT2: J1#2.3, J2.2
Board_1-OUT_1: D1#2.4 (DI), D3#2.4 (DI), U2.4 (Y)
Board_1-V_IN: D2.2 (A), J1#2.8

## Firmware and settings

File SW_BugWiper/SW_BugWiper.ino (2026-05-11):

#include <Arduino.h>
#include "BugWiper.h"
#include "my_debug.h"
#include "sd_logger.h"

#define FIRMWARE_VERSION "V0.1"

//The setup function is called once at startup of the sketch
void setup() {
  DEBUG_INIT(115200);
  bw_rgbLed_init();
  bw_init();
  sdLoggerInit();
  while(millis() < 600) {
    delay(100);
  }
  bw_rgbLedWrite(BLACK);
  sdLoggerOpenLogLater();
  while(millis() < 1200) {
    delay(100);
  }
  if (sdLoggerAvailable()) {
    bw_rgbLedWrite(GREEN);
  } else {
    bw_rgbLedWrite(ORANGE);
  }
  delay(300);
  bw_rgbLedWrite(BLACK);
  DEBUG_INFO("BugWiper start programm");
  bw_log();
}

// The loop function is called in an endless loop
void loop() {
  sdLoggerHandleCard();
  if(bw_currentMode!=M_IDLE){
    bw_log();
  }
  //bw_btn_log();
  delay(500);
}

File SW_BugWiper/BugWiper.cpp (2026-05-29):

#include "esp32-hal-gpio.h"
#include "esp32-hal-adc.h"
#include "esp32-hal-ledc.h"
#include <sys/_stdint.h>
#include <Arduino.h>
#include "my_debug.h"
#include "BugWiper.h"
#include "btn99x0_motor_control.hpp"
#include "sd_logger.h"

#define ADC_FILTER_SIZE 32

// Task periods in ms
#define BW_TASK_FAST_MS  2
#define BW_TASK_SLOW_MS  20

// Stop function thresholds
#define BW_STOP_CURRENT 6500
#define BW_STOP_CURRENT_COUNTS 5
#define BW_STOP_SPEED 1
#define BW_STOP_SPEED_COUNTS 20
#define BW_STOP_V_BAT 8.0
#define BW_STOP_T_MAX 70

// Sensor filter parameters (more stable)
#define BW_SENSOR_FILTER_THRESHOLD  30
// Button filter parameters (fast reaction)
#define BW_BTN_FILTER_THRESHOLD  10
#define BW_BTN_DEBOUNCE_TICKS  3    // fast task ticks
#define BW_BTN_HOLD_TICKS     100  // fast task ticks

// String representation of BW_MODE for logging and debugging
static const char* BW_MODE_STR[BW_MODE_COUNT] = {
  "IDLE",
  "REFERENCE_IN",
  "START_CLEAN_OUT",
  "CLEANING",
  "DECEL_LOOSE",
  "WIGGLE_IN",
  "WIGGLE_OUT",
  "DECEL_END",
  "WINDING_IN",
  "WINDING_IN_DECEL",
  "GROUND_OUT",
  "DECEL_LOOSE_GROUND",
  "FINISHED",
  "EMERGENCY_IN",
  "STOP",
  "ERROR"
};

const char* bw_ModeToString(BW_MODE mode)
{
  if (mode >= BW_MODE_COUNT) {
    return "INVALID_MODE";
  }
  return BW_MODE_STR[mode];
}

// Mode configuration table indexed by BW_MODE
const BW_ModeConfig bw_modeConfig[BW_MODE_COUNT] = {

  /* ------------------------------------------------------------
   * M_IDLE
   * ------------------------------------------------------------ */
  {
    // Motor behavior
    .motorCmd = {
      .dir         = STOP,
      .startPower  = 0,
      .targetPower = 0,
      .rampTime    = 0
    },

    // LED behavior
    .ledCmd = {
      .color     = BLACK,
      .blinkTime = 0
    },

    // Timing
    .minTime = 0,
    .maxTime = 0,

    // Global transition flags
    .enableEndCheckCurrent = false,
    .enableEndCheckSpeed   = false,
    .enableSafetyProtection = false,
    .enableMaxTimeCheck    = false,
    .enableStopRequest     = false,
    .enableWingTipCheck    = false,
    .requireMinTimeForEndCheck = false,

    .defaultNext = M_IDLE
  },

  /* ------------------------------------------------------------
   * M_REFERENCE_IN
   * ------------------------------------------------------------ */
  {
    .motorCmd = {
      .dir         = IN,
      .startPower  = 80,
      .targetPower = 200,
      .rampTime    = 20
    },

    .ledCmd = {
      .color     = GREEN,
      .blinkTime = 100
    },

    .minTime = 1000,
    .maxTime = 5000,

    // Global transition flags
    .enableEndCheckCurrent = false,
    .enableEndCheckSpeed   = false,
    .enableSafetyProtection = true,
    .enableMaxTimeCheck    = true,
    .enableStopRequest     = true,
    .enableWingTipCheck    = false,
    .requireMinTimeForEndCheck = false,

    .defaultNext = M_START_CLEAN_OUT
  },

  /* ------------------------------------------------------------
   * M_START_CLEAN_OUT
   * ------------------------------------------------------------ */
  {
    .motorCmd = {
      .dir         = OUT,
      .startPower  = 40,
      .targetPower = 150,
      .rampTime    = 15
    },

    .ledCmd = {
      .color     = GREEN,
      .blinkTime = 400
    },

    .minTime = 500,
    .maxTime = 5000,

    // Global transition flags
    .enableEndCheckCurrent = true,
    .enableEndCheckSpeed   = false,
    .enableSafetyProtection = true,
    .enableMaxTimeCheck    = true,
    .enableStopRequest     = true,
    .enableWingTipCheck    = true,
    .requireMinTimeForEndCheck = false,  // minTime > 0

    .defaultNext = M_CLEANING
  },

  /* ------------------------------------------------------------
   * M_CLEANING
   * ------------------------------------------------------------ */
  {
    .motorCmd = {
      .dir         = OUT,
      .startPower  = 0,
      .targetPower = 255,
      .rampTime    = 7
    },

    .ledCmd = {
      .color     = GREEN,
      .blinkTime = 400
    },

    .minTime = 250,
    .maxTime = 15000,

    // Global transition flags
    .enableEndCheckCurrent = true,
    .enableEndCheckSpeed   = true,
    .enableSafetyProtection = true,
    .enableMaxTimeCheck    = true,
    .enableStopRequest     = true,
    .enableWingTipCheck    = true,
    .requireMinTimeForEndCheck = true,

    .defaultNext = M_DECEL_END
  },

  /* ------------------------------------------------------------
   * M_DECEL_LOOSE
   * ------------------------------------------------------------ */
  {
    .motorCmd = {
      .dir         = STOP,
      .startPower  = 0,
      .targetPower = 0,
      .rampTime    = 0
    },

    .ledCmd = {
      .color     = ORANGE,
      .blinkTime = 400
    },

    .minTime = 700,
    .maxTime = 10000,

    // Global transition flags
    .enableEndCheckCurrent = false,
    .enableEndCheckSpeed   = false,
    .enableSafetyProtection = true,
    .enableMaxTimeCheck    = true,
    .enableStopRequest     = true,
    .enableWingTipCheck    = true,
    .requireMinTimeForEndCheck = false,

    .defaultNext = M_START_CLEAN_OUT
  },

  /* ------------------------------------------------------------
   * M_WIGGLE_IN
   * ------------------------------------------------------------ */
  {
    .motorCmd = {
      .dir         = IN,
      .startPower  = 70,
      .targetPower = 85,
      .rampTime    = 1
    },

    .ledCmd = {
      .color     = BLUE,
      .blinkTime = 400
    },

    .minTime = 0,
    .maxTime = 1000,

    // Global transition flags
    .enableEndCheckCurrent = false,
    .enableEndCheckSpeed   = false,
    .enableSafetyProtection = true,
    .enableMaxTimeCheck    = true,
    .enableStopRequest     = true,
    .enableWingTipCheck    = true,
    .requireMinTimeForEndCheck = false,

    .defaultNext = M_WIGGLE_OUT
  },

  /* ------------------------------------------------------------
   * M_WIGGLE_OUT
   * ------------------------------------------------------------ */
  {
    .motorCmd = {
      .dir         = OUT,
      .startPower  = 30,
      .targetPower = 100,
      .rampTime    = 10
    },

    .ledCmd = {
      .color     = ORANGE,
      .blinkTime = 400
    },

    .minTime = 370,
    .maxTime = 5000,

    // Global transition flags
    .enableEndCheckCurrent = false,
    .enableEndCheckSpeed   = false,
    .enableSafetyProtection = true,
    .enableMaxTimeCheck    = true,
    .enableStopRequest     = true,
    .enableWingTipCheck    = true,
    .requireMinTimeForEndCheck = false,

    .defaultNext = M_CLEANING
  },

  /* ------------------------------------------------------------
   * M_DECEL_END
   * ------------------------------------------------------------ */
  {
    .motorCmd = {
      .dir         = OUT,
      .startPower  = 0,
      .targetPower = 0,
      .rampTime    = 4
    },

    .ledCmd = {
      .color     = GREEN,
      .blinkTime = 0
    },

    .minTime = 0,
    .maxTime = 1500,
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

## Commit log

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2016-07-04 Belegung des Arduino Nano V3
    [Belegung_ArduinoNanoV3.csv]
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2016-07-04 Umbenennung von Putzen_PIN und EIn_Ziehen_PIN zur Vorbereitung auf zweiten Motor
    [Belegung_ArduinoNanoV3.csv]
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2016-07-10 change putzen und einziehen Pin von motor B um die serielle Schnittstelle zum Debuggen benutzen zu können
    [Belegung_ArduinoNanoV3.csv]
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2016-07-12 Belegung der Stecker hinzugefügt
    [Belegung_ArduinoNanoV3.csv]
2016-07-16 Änderung der Pin Belegung
    [Belegung_ArduinoNanoV3.csv]
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2024-02-12 add serial debug output. change GPI Pins to fix restart and pwm init problem
2024-02-12 Update BugWiper2_0.ino
    #if for dual Motor Pin definition
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2024-02-13 fix PWM
2024-02-13 debug info if cable loose
    [SW_BugWiper.ino]
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2024-02-18 change PINs, remove tight switch, add encoder to motor b
    [ESP32_PINs.csv]
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2024-02-24 fix previous comment and delete eeprom and direction change
    [SW_BugWiper.ino]
2024-02-24 fix state machine motor b and move over current shutdown to state machine
    [SW_BugWiper.ino]
2024-03-23 Move the BugWiper functions in a class and to file BugWiper.cpp
    [BugWiper.cpp, BugWiper.h, SW_BugWiper.ino]
2024-04-09 First CAD model of the spool and the flange
    [Rigid_Flange_6mm.FCStd, Spool_38mm.FCStd, Spool_38mm.stl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]
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2024-04-26 compare different motors in a csv table
    [Motor_calculation.csv]
2024-04-28 new state machine for the BugWiper. new tranforation of the motorencoder to the position in mm
    [BugWiper.cpp, BugWiper.h, SW_BugWiper.ino]
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2025-01-02 fix dual init of bugwiper
    [SW_BugWiper.ino]
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2025-01-03 move calculation to main and fix devide by zero
    [BugWiper.cpp, BugWiper.h, SW_BugWiper.ino]
2025-01-04 add new motors to the motor calculation.csv
    [Motor_calculation.csv]
2025-01-06 Add Excel File to compare different Motors and calculate Speeds and Forces
    [Motor_calculation.csv, Motor_comparison.csv, Motor_comparison.xlsx]
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2025-01-08 start KiCAD Project and libs
    [BugWiperPCB.kicad_pcb, BugWiperPCB.kicad_sch, ESP32-S3.kicad_sch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]
2025-01-09 Add USB-C and Buttons to the Schematics, PCB and BOM
    [BugWiperPCB.kicad_pcb, ESP32-S3.kicad_sch]
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2025-01-16 update PCB
    add 12V to 3.3V converter and 5V to 3.3V for USB
    add protections to the RJ45
    component placement
    [BugWiperPCB.kicad_pcb, BugWiperPCB.kicad_sch, ESP32-S3.kicad_sch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]
2025-01-17 add ESD protection to inputs
    [BugWiperPCB.kicad_pcb, BugWiperPCB.kicad_sch, ESP32-S3.kicad_sch]
2025-01-18 add debug connector, arrange foodprints and add NTC and connect to GPIOs to ESP32
    [BugWiperPCB.kicad_pcb, BugWiperPCB.kicad_sch, ESP32-S3.kicad_sch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]
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2025-01-19 update PCB, routing and Connector
    [BugWiperPCB.kicad_pcb, BugWiperPCB.kicad_sch, ESP32-S3.kicad_sch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]
2025-01-19 turn the esp32 90°
    [BugWiperPCB.kicad_pcb]
2025-01-20 routing and change to 4 layer PCB
    [BugWiperPCB.kicad_pcb, BugWiperPCB.kicad_sch]
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2025-01-22 Update PCB
    add Connector for Sw_2, add voltage devider for the encoder
    [BugWiperPCB.kicad_pcb, BugWiperPCB.kicad_sch, ESP32-S3.kicad_sch]
2025-01-24 update PCB
    Add voltage selector solder jumper vor rj45 connector to switch between 12V and 3.3V vor the control panel
    Add voltage supression diodes for IS pins from the motor driver ICs
    Fix DRC violations
    [BugWiperPCB.kicad_pcb, ESP32-S3.kicad_sch, Power.kicad_sch]
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2025-01-27 update PCB and add a second PCB as a Controlpanel with a dual toggle switch and rgb LED
    [BugWiperPCB.kicad_pcb, ESP32-S3.kicad_sch, MJ3415-88-2.stp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]
2025-01-27 Add a micro SD Card slot to the bottom of the controller board
    [BugWiperPCB.kicad_pcb, BugWiperPCB.kicad_sch, ESP32-S3.kicad_sch]
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2025-01-27 export schematics as PDF
    [BugWiperPCB.kicad_sch]
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2025-01-28 update Controller PCB
    Add Fuses for GND Signal Connectors, fix 3D and fix DRC
    [BugWiperPCB.kicad_pcb, BugWiperPCB.kicad_sch, ESP32-S3.kicad_sch]
2025-01-28 export Gerber, edit text
    [BugWiperPCB-B_Cu.gbr, BugWiperPCB-B_Mask.gbr, BugWiperPCB-B_Paste.gbr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]
2025-01-29 Update PCB
    Add solder jumper for +3.3V selection
    fix DRC
    aligne vias
    export Gerber
    add text
    fix 3D Models
    [BugWiperPCB-B_Cu.gbr, BugWiperPCB-B_Mask.gbr, BugWiperPCB-B_Paste.gbr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]
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2025-01-30 update Controller PCB
    Add additional capacitor
    fix footprint Resistor Array CAT16
    fix 3D Model CAT16
    change traces from 0.5 to 0.4 mm
    fix USB-C Footprint
    Export Gerber
    update BOM and Values
    [BugWiperPCB-B_Cu.gbr, BugWiperPCB-B_Mask.gbr, BugWiperPCB-B_Paste.gbr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]
2025-01-30 update PanelPCB and generade a DualPanelPCB
    [DoublePanel_MouseBites-B_Cu.gbr, DoublePanel_MouseBites-B_Mask.gbr, DoublePanel_MouseBites-B_Paste.gbr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]
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2025-02-04 update PCB and Gerber
    change Switches to cheaper ones
    [BugWiperPCB-B_Cu.gbr, BugWiperPCB-B_Mask.gbr, BugWiperPCB-B_Paste.gbr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]
2025-02-18 update PCB to view Values and Refs
    [BugWiperPCB.kicad_pcb, BugWiperPCB.kicad_sch, ESP32-S3.kicad_sch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]
2025-02-24 update Controller PCB PDF Export and layer of Values and Reference
    [BugWiperPCB.kicad_pcb, ESP32-S3.kicad_sch, Power.kicad_sch]
2025-02-26 Export PCBs as Step and start CAD construction
    [BugWiperPCB.kicad_pcb, DoublePanel_MouseBites.kicad_pcb, Housing.FCStd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]
2025-02-26 prepare software for new PCB
    [ESP32_PINs.csv]
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2025-05-10 export PDF with dimension of the PCB
    [BugWiperPCB.kicad_pcb]
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2025-05-10 update motor CAD model
    [5840_geared_motor.FCStd]
2025-05-18 go back to c function for the bugwiper
    [BugWiper.cpp, BugWiper.h, SW_BugWiper.ino]
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2025-05-19 fix schematics and pins for the encoder
    [BugWiperPCB.kicad_pcb, BugWiperPCB.kicad_sch, ESP32-S3.kicad_sch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]
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2025-05-19 add calculations for INA current sense
    [Power.kicad_sch]
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2025-05-20 move motor encoder to BugWiper.cpp
    [BugWiper.cpp, BugWiper.h, SW_BugWiper.ino]
2025-05-20 spoole housig is finished and ready for export
    [BugWiperSystem.FCStd, Motor_housing.FCStd, Spool_housing-Spool Housing.stl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]
2025-05-20 fix CAD Model
    [BugWiperSystem.FCStd, Motor_housing.FCStd, Spool_housing-Spool Housing.stl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]
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2025-05-22 read buttons. implements two tasks for the BugWiper system
    [BugWiper.cpp, BugWiper.h, SW_BugWiper.ino]
2025-05-22 fix start BugWiper and cleaning code
    [BugWiper.cpp, BugWiper.h, SW_BugWiper.ino]
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2025-05-23 add TESTBENCH mode, check for end reached, check for cabel loose
    [BugWiper.cpp, BugWiper.h, SW_BugWiper.ino]
2025-05-24 add second state machine timer to brake and pause the motot at the wingtip to prevent high current spikes when changing the direction
    [BugWiper.cpp]
2025-05-24 reset the encoder position to zero befor starting a new cleaning circle
    [BugWiper.cpp]
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2025-06-02 fix position motor holes and position of the motor
    [Motor_housing_2-Motor_housing.stl, Motor_housing_2.FCStd]
2025-06-02 fix fillet radius of the cover, add bigger pocket for the connector of the switch
    [Spool_housing_2-Spool Housing.stl, Spool_housing_2-Spool_Housing_2_cover.stl, Spool_housing_2.FCStd]
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2025-06-02 fix hole size and position
    [defelction_pulley.FCStd]
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2025-06-02 update controller PCB: change Encoder filter to 1nF add 0 Ohm resistor for JP1 to BOM
    [BugWiperPCB.kicad_pcb, BugWiperPCB.kicad_sch, ESP32-S3.kicad_sch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]
2025-06-03 fix motorhousing2
    [BugWiperSystem.FCStd, Motor_housing_2-Motor_housing.stl, Motor_housing_2.FCStd]
2025-11-11 Add a new smaller version of the deflection pulley that is parametric and export it in different angels from 45° to 120°.
    [Deflection_Pulley_5mm_105Deg.stl, Deflection_Pulley_5mm_120Deg.stl, Deflection_Pulley_5mm_30Deg.stl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]
2025-11-11 fix empty stl files
    [Deflection_Pulley_5mm_105Deg.stl, Deflection_Pulley_5mm_120Deg.stl, Deflection_Pulley_5mm_30Deg.stl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]
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2025-11-11 update CAD Model and export Housing as stl
    [BugWiperSystem.FCStd, Coin_Switch_2.FCStd, Connector_Cover_V2.stl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]
2026-04-18 update to FreeCad 1.1 and add slots for screw of the motor housing
    [5840_geared_motor.FCStd, BugWiperSystem.FCStd, BugWiper_Controller_PCB.FCStd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]
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2026-04-18 add a slot for the micro sd kart to the motor housing
    [BugWiperSystem.FCStd, BugWiperSystem_Bambu.3mf, Motor_housing_2.FCStd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]
2026-04-18 move the cutouts in the connector cover 1,5mm to the left
    [BugWiperSystem.FCStd, BugWiperSystem_Bambu.3mf, Connector cover_2.stl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]
2026-04-18 Add SD Card logging to the bugwiper
    [SW_BugWiper.ino, sd_logger.cpp]
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2026-04-27 fsm: migrate to explicit finite state machine (WIP, builds)
    This commit introduces a new explicit finite state machine (FSM)
    architecture based on BW_MODE and ModeConfig.
    Changes include:
    - Replace legacy numeric state machine with BW_MODE enum
    - Introduce state<Mode>() functions and centralized processFSM()
    - Add ModeConfig table for mode-specific behavior
    - Separate motor command intent from motor power ramping
    - Introduce PositionConfig for geometry-dependent limits
    - Add ground mode with limited outward travel
    - Update logging to use symbolic FSM state names
    The code now compiles successfully, but several states are still
    implemented as stubs and require final logic integration
    (e.g. r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
    [BugWiper.cpp, BugWiper.h, SW_BugWiper.ino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]
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2026-05-01 Refactor BugWiper codebase for consistency and clarity by renaming functions and variables, updating logging methods, and consolidating threshold definitions.
    [BugWiper.cpp, BugWiper.h, SW_BugWiper.ino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]
2026-05-01 Refactor BugWiper to use structured data for ADC filtering, motor state, and button states, enhancing code clarity and maintainability.
    [BugWiper.cpp, BugWiper.h]
2026-05-01 update CAD files.: Add slot for the cable and a cutout for the sd card
    [5840_geared_motor.FCStd, BugWiperSystem.FCStd, BugWiperSystem_Bambu.3mf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]
2026-05-01 Refactor BugWiper code to enhance button handling and filtering mechanisms, introducing BwFilter and ButtonRuntime structures for improved state management and debounce logic.
    [BugWiper.cpp, BugWiper.h, SW_BugWiper.ino]
2026-05-02 Refactor BugWiper mode configuration to replace behavior flags with global transition flags, enhancing end position checks and safety mechanisms.
    [BugWiper.cpp, BugWiper.h]
2026-05-03 Refactor BugWiper state management by removing BW_SubState enum and simplifying state handling logic in various functions.
    [BugWiper.cpp, BugWiper.h]
2026-05-03 Add cable loose check in stateWiggleLoose to transition modes
    [BugWiper.cpp]
2026-05-03 Increase stack size for BugWiper_Task1_fast to prevent Stack-Overflow
    [BugWiper.cpp]
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2026-05-03 Invert button state readings in BugWiper_Task1_fast for correct logic handling
    [BugWiper.cpp]
2026-05-03 Update BugWiperSystem_Bambu.3mf file for improved housing design
    [BugWiperSystem_Bambu.3mf]
2026-05-03 Reset lastUserCommand to CMD_NONE in stateFinished, stateStop, and stateError functions for improved state management
    [BugWiper.cpp]
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2026-05-03 Enable cable loose switch inversion
    [BugWiper.h]
2026-05-03 Move button state updates to slow task to fix button event detection
    [BugWiper.cpp]
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2026-05-03 Refactor encoder handling: consolidate encoder reset logic , improve reading function and add reset function
    [BugWiper.cpp]
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2026-05-03 Update default next mode to IDLE to fix encoder reset after stop and log event on mode change
    [BugWiper.cpp]
2026-05-03 Update PCB files and documentation for BugWiper 2.0: change revision to V1.2, update value from C4 from 100nF to 470nF
    [BugWiperPCB.kicad_pcb, BugWiperPCB.kicad_sch, ESP32-S3.kicad_sch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]
2026-05-03 Update PCB documentation: add test results and correct C4 capacitor value to 470nF
2026-05-04 Implement wiggle mode logic: add parameters and state management for cable tightness detection
    [BugWiper.cpp]
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2026-05-04 Update default next mode to CLEANING for improved workflow after loose detection
    [BugWiper.cpp]
2026-05-04 Add DECEL_LOOSE_GROUND mode for improved cable loose handling in ground mode
    [BugWiper.cpp, BugWiper.h]
2026-05-04 Fix typos in comments for clarity and consistency
    [BugWiper.cpp, BugWiper.h]
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2026-05-05 fix transition conditions from WindingIn to WindingInDecel
    [BugWiper.cpp]
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2026-05-07 update CAD model and export stls in higher resolution
    [5840_geared_motor.FCStd, BugWiperSystem.FCStd, BugWiperSystem_Bambu.3mf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]
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2026-05-09 invert Ground Switch
2026-05-09 fix Ground Mode
2026-05-11 redesign wiggle in and out
    [BugWiper.cpp, BugWiper.h]
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2026-05-11 add cable loose to logging
    [BugWiper.cpp, sd_logger.cpp]
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
